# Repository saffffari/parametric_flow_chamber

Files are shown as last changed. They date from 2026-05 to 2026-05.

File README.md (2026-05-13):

# Parametric Flow Chamber

Open-source, parametric, parallel-plate perfusion flow chamber for delivering programmable wall-shear-stress waveforms to MLO-Y4 osteocyte-like cells on a Zeiss LSM 880 inverted multiphoton microscope. Includes hardware CAD, Teensy 4.1 firmware, and an Electron operator app with a synth-style control surface.

This repo is the companion to the paper. A first-time reader should be able to fabricate the chamber, flash the firmware, run the controller app, and reproduce paper figures from this single repository.

## Quickstart

| Goal | Path |
|---|---|
| Understand the science | [`docs/theory.md`](docs/theory.md) → [`docs/architecture.md`](docs/architecture.md) |
| Run the wet-lab protocol | [`docs/protocol.md`](docs/protocol.md) |
| Fabricate the chamber | [`hardware/bom.md`](hardware/bom.md) → [`hardware/assembly.md`](hardware/assembly.md) → [`hardware/machining_notes.md`](hardware/machining_notes.md) → vendor PDFs in [`hardware/drawings/`](hardware/drawings) |
| Flash the firmware | [`firmware/README.md`](firmware/README.md) |
| Run the operator app | [`app/README.md`](app/README.md) |
| Reproduce a paper figure | [`docs/reproducing.md`](docs/reproducing.md) (TBD) |

## What this is

A laminar parallel-plate perfusion chamber where the operator dials a single wall-shear-stress waveform in physical units (Pa). All other engineering quantities — flow rate, step pulse rate, microstepping, motor current — derive from chamber geometry, media viscosity, and the shear setpoint. The operator never sees an RPM.

The chamber:

- 316L stainless body, electropolished and passivated wetted surfaces.
- 24 mm × 50 mm × 0.25 mm channel under a Thorlabs CG15KH1 #1.5H cover glass.
- Inverted-microscope geometry: cells on the cover-glass floor, objective images from below.
- Autoclavable. No RTV silicone. No acetoxy-cure adhesives.

The controller:

- Teensy 4.1 + TMC2209 stepper driver running PlatformIO firmware.
- Inline liquid flow measurement via Sensirion SLF3S-1300F (PEEK-wetted, in the controller body, reports flow rate + media temperature on the same I²C frame).
- Closed-loop control on wall shear stress via direct flow + Hagen-Poiseuille geometry mapping.
- Optically-isolated BNC trigger to/from the microscope.
- microSD log of every sample, time-aligned with each LSM 880 frame.

In-loop measurement is via direct liquid flow (SLF3S-1300F). The differential-pressure approach is described in the methods section as a one-time per-chamber validation step, not as a deployed-device sensor; see `docs/protocol.md` for the validation procedure and `hardware/electronics/README.md` for the architecture.

The app:

- Electron + React + TypeScript with a synth-style control panel (OSC / SHEAR / ENV / DISPLAY / SYNC / TRANSPORT / MASTER).
- Mock-first: full development without hardware.
- Folder-based study persistence (JSON + CSV per run, no proprietary container).
- Mac (`.dmg`) and Windows (`.exe`/`.msi`) builds.

## Repo layout

- `docs/` — theory, architecture, protocol, design language, reproducing-a-figure recipes
- `hardware/` — BOM, assembly, machining notes, CAD source + STEP + drawings, electronics
- `firmware/` — PlatformIO project for Teensy 4.1
- `app/` — Electron + React + TypeScript operator app
- `examples/` — sample folder-based study and figure-regen scripts
- `.github/` — issue templates and CI workflows

## Status

This is the v2.0 release: the first public release. v1.0 was an undergraduate honors thesis prototype (Saffari, Cornell, 2024) that was not publicly released; v2.0 is a full rebuild with a parametric CAD source, a deterministic-timing firmware, and a new operator app on the Electron stack. See [`CHANGELOG.md`](CHANGELOG.md).

## Citing this work

If you use this chamber, the firmware, the app, or methods derived from this repository in academic work, please cite both the paper and the software archive.

**Software** (this repository):

```
Saffari, A., Rocca, I., Matthews, M., & Lewis, K. (2026).
Parametric Flow Chamber (v2.0).
[DOI / GitHub URL TBD on publication]
```

**Paper** (the methods paper this repository accompanies): TBD on publication.

A machine-readable citation file is in [`CITATION.cff`](CITATION.cff). GitHub renders the "Cite this repository" button from it.

## License

- **Code** (`firmware/`, `app/`, scripts in `examples/`): [MIT License](LICENSE).
- **Hardware and documentation** (`hardware/`, `docs/`, `examples/figures/`): [Creative Commons Attribution 4.0 International](LICENSE-HARDWARE).

These are the standard JOSS-aligned pair for open-source hardware companions to academic papers. You may use, modify, fabricate, and redistribute under these terms; please give appropriate credit and indicate any changes you made.

## Contributing

Issues and pull requests are welcome — see [`CONTRIBUTING.md`](CONTRIBUTING.md). Use the issue templates for bug reports, feature requests, and hardware questions.

## Acknowledgements

Cell line: MLO-Y4 (Bonewald lab, U. Missouri-Kansas City; gift; Lu et al. 2012). In vivo loading framework: Lewis et al. 2017 (Cornell). Machining: vendor TBD. Microscopy: Cornell Imaging Facility.

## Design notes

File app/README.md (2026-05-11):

# Flow Chamber operator app

Electron + React + TypeScript operator app for the parametric flow chamber. Drives the Teensy 4.1 firmware over USB serial, manages folder-based studies (JSON + CSV per run), and exposes a synth-style control surface in a Drams/Rams-influenced visual language.

## Stack

- **Electron 33** + electron-forge (with Vite plugin) — shell, packaging, signing
- **React 18 + TypeScript + Vite** — renderer
- **Tailwind v4** + Radix UI primitives + shadcn-style components — UI
- **motion** — animations, rotating-wheel inertia
- **Zustand** — app state (studies, runs, UI)
- **uPlot** — real-time telemetry plotting (~50 KB, made for streaming)
- **serialport** — Teensy serial; works on Mac (`/dev/cu.usbmodem*`) and Windows (`COM*`)
- **fs-extra + csv-parse** — study folder I/O
- **electron-store** — settings persistence
- **Vitest** + **Playwright** — unit + E2E testing

## Develop

```bash
cd app
npm install
npm start     # electron-forge start — launches the app in dev mode with hot reload
```

The dev build defaults to **mock mode**: a simulated Teensy interface produces realistic shear-vs-time waveforms (sine, square, triangle, DC). No hardware required.

## Build

```bash
npm run make
```

Builds platform-native installers under `out/make/`:

- macOS: `.dmg` (Intel + Apple Silicon)
- Windows: `.exe` (Squirrel) and `.msi`

## Test

```bash
npm run typecheck      # tsc --noEmit
npm run lint           # ESLint
npm run test:unit      # Vitest
npm run test:e2e       # Playwright
```

## Architecture

(Stubs only at this point — implementation per `planning/HANDOFF.md` § "v1 app scope (trimmed first slice)" follows in subsequent sessions.)

```
app/
├── electron/             # main process + preload
│   ├── main.ts           # window lifecycle, IPC handlers, native module bridge
│   └── preload.ts        # contextBridge API surface to the renderer
├── src/                  # renderer (React)
│   ├── main.tsx          # React entry
│   ├── App.tsx           # root shell (sidebar + main + footer)
│   ├── components/       # UI components (control panel blocks, knobs, widgets)
│   ├── domain/           # shear math, storage schemas, run lifecycle
│   ├── lib/              # mock interface, serial transport, study I/O
│   └── styles/           # globals.css with design tokens
├── tests/                # Vitest + Playwright tests
├── forge.config.ts       # electron-forge packaging config
├── vite.{main,preload,renderer}.config.ts
└── tsconfig.json
```

## Mock vs hardware mode

`app/src/lib/mock-interface.ts` is the in-process simulator. It produces realistic telemetry for development without the Teensy. The same interface can be backed by `app/src/lib/serial-interface.ts` (real Teensy via `serialport`) when running against hardware.

The HANDOFF v1 scope ships **mock-only**. Real serial connectivity ships in v2 once the firmware command set is finalized.

## Folder-based study format

Studies persist as folders containing JSON + CSV. The wire format is identical to the Python v0.1 controller (preserved at `archive/flow_chamber_v1/python_v0.1_app/` — outside the public repo) so old and new tooling cross-read. Sample at `examples/demo_study/`.

## Design language

See `docs/design_language.md`. Hardware aesthetic: TX-6-influenced precision instrument. Software aesthetic: Drams/Rams sibling visual language. Tokens come from the project Figma file (file key `J3aZzdLaJmidPQcOxphPdE`, root frame node `2004-140`) via the Figma MCP — replace placeholder values in `src/styles/globals.css` once authenticated.

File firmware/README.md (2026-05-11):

# Flow Chamber Teensy Firmware

Dry bench firmware for the Teensy 4.1 controller. This first target only proves
the Teensy, USB serial, onboard LED, and onboard microSD logging. It does not
drive fluidics.

## Hardware For This Step

- Teensy 4.1
- USB cable
- microSD card in the Teensy 4.1 onboard socket, optional but recommended

Do not connect the pump, TMC2209, or microscope trigger during this first smoke
test.

## Build And Upload

This project uses PlatformIO. A local PlatformIO environment has been created in
`.venv`, so these commands work even if `pio` is not globally installed:

```powershell
cd "D:\research\parametric flow chamber\firmware"
.\.venv\Scripts\pio.exe run -e teensy41
.\.venv\Scripts\pio.exe run -e teensy41 -t upload
.\.venv\Scripts\pio.exe device monitor -b 115200
```

During upload, press the Teensy program button if PlatformIO/Teensy Loader asks
for it.

## Serial Smoke Test

Open the serial monitor at `115200` baud and send:

```text
PING
STATUS?
LOGTEST
STOP
```

Expected responses:

```text
PONG flow_chamber_teensy_smoke 0.1.0
OK name=flow_chamber_teensy_smoke version=0.1.0 state=READY ...
OK wrote SMOKE00.CSV
OK pump outputs disabled
```

The onboard LED should blink twice per second. If a microSD card is present, the
firmware creates `SMOKE00.CSV`, `SMOKE01.CSV`, etc. with heartbeat rows.

## Dry STEP Test

Before wiring the TMC2209 or pump, verify the STEP output with a logic analyzer:

- logic analyzer `GND` to Teensy `GND`
- logic analyzer channel 0 to Teensy pin `2`

Commands:

```text
STEPTEST 100 5000
STATUS?
STEPTEST 1000 5000
STOP
```

`STEPTEST` pulses pin `2`, but keeps the TMC2209 enable pin disabled. The second
argument is duration in milliseconds. The firmware auto-stops after the duration.

## Dry Motor Jog

Only use `JOG` after the TMC2209 is wired correctly, current is set low, the 24 V
rail is fused, and no tubing or liquid is installed.

Initial command:

```text
JOG 100 3000
STOP
```

`JOG` enables the TMC2209 enable pin, pulses STEP, and auto-stops after the
requested duration. Duration is capped at 30 seconds. Use `DIR 0` or `DIR 1` to
change direction, but only while stopped.

## Safety Defaults

Pin 4 is configured as the future TMC2209 `ENABLE` pin and is driven disabled on
boot. Most TMC2209 carrier boards use active-low enable, so this firmware drives
that pin high and reports `pump=disabled` in `STATUS?`.

Command safety behavior:

- `STOP` ends the timer and drives TMC2209 `ENABLE` disabled.
- `STEPTEST` never enables the driver.
- `JOG` is time-limited and auto-stops.
- Direction changes are rejected while step pulses are active.

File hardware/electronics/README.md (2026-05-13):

# Electronics — controller, pressure, and bring-up

> Merged from `electronics_controller_architecture.md`, `chamber_pressure_system.md`, and `electronics_bringup_checklist.md` from the dev archive. Section dividers (`---`) preserve source boundaries; source heading levels demoted by one level.

## Contents

1. **Controller Architecture** — Teensy 4.1 + TMC2209 stepper driver + isolated BNC trigger interface; pump control strategy; safety architecture; tentative Teensy pin map; firmware module layout.
2. **Flow & Shear Measurement System** — Sensirion SLF3S-1300F inline liquid flow sensor in the controller; closed-loop shear stabilization via flow + Hagen-Poiseuille geometry mapping; pulsation dampeners; digital twin; LSM 880 frame-marker time alignment; calibration protocol. Per-chamber validation against a separate gas-side differential-pressure rig (DFRobot SEN0343 / All Sensors LWLP5000 + standpipes + Millex-FG separators) is described under "Validation methodology" and `docs/protocol.md` § "Per-chamber sensor validation".
3. **Bench Bring-Up Checklist** — the procedural test sequence; bench setup table; suggested first wiring map; pump calibration; microscope trigger validation; wet-run gate.

> **Cross-references:** body sections reference `design_spec_v2.md` (split → `docs/theory.md` + `docs/architecture.md`) and `Sensor Survey for Wall Shear Stress.md` (moved → `literature/sensor_survey_wall_shear.md`). In-body cross-references have **not** been updated.

> **Geometry note:** the pressure-system section uses the canonical 24 mm × 50 mm × 0.25 mm geometry with μ = 0.9 mPa·s. The bring-up section is geometry-independent.

---

## Electronics And Controller Architecture

This document is the working controller design for the open-source flow chamber. It supersedes the electronics assumptions in `2photon_flow_chamber_v2.md` where the two conflict.

Goal: make the chamber behave like a small research instrument, not a pile of lab electronics. The controller must deliver repeatable shear stimulus, log the exact stimulus timing, and remain buildable by an undergraduate lab. Microscope protection comes from chamber design (sealed, autoclavable, no exposed electrodes) and operator-side visual monitoring; dedicated leak detection is out of scope for the current spec.

### Primary Decision

Use the Teensy 4.1 as the real-time controller.

Use the ESP32-S3 only as an optional wireless/status coprocessor later. It should not own pump timing, microscope trigger timing, or the authoritative experiment log.

Why:

- Teensy 4.1 has deterministic timers, native high-speed USB, onboard microSD, many serial/SPI/I2C ports, and enough GPIO for this system.
- ESP32-S3 is excellent for WiFi/BLE, but wireless and RTOS scheduling should not sit in the critical path for pump timing or safety shutdown.
- The open-source reference build should work without WiFi, cloud services, or network configuration.

### System Roles

| Function | Primary implementation | Notes |
|---|---|---|
| Pump timing | Teensy 4.1 hardware timer | Step pulse generation must not depend on laptop timing |
| TMC2209 configuration | Teensy UART | Current, microstepping, diagnostics |
| Flow protocol engine | Teensy state machine | Baseline, ramp, hold, recovery |
| Temperature logging | DS18B20 probes on Teensy OneWire | Reservoir, inlet, ambient/stage |
| Pump shutdown | Hard 24 V enable cut + firmware STOP | Physical switch/fuse on the motor rail; firmware-side STOP disables the TMC2209 ENABLE pin |
| Microscope sync | Isolated BNC trigger board | The i880 interface must remain electrically isolated |
| Experiment log | Teensy microSD | Teensy timestamp is authoritative |
| Live GUI | Laptop over USB serial | Optional for run control and plotting |
| Local display | Waveshare OLED on Teensy SPI | Useful for standalone status |
| Wireless mirror | ESP32-S3 optional | Telemetry viewer only, not safety-critical |

### Practical Electrical Architecture

The original notes proposed three fully galvanically isolated domains. That is the right instinct for the microscope, but it is too easy to claim false isolation with a commodity TMC2209 module.

Most TMC2209 carrier boards tie motor ground and logic ground together. If the Teensy drives the TMC2209 while both boards share ground, optocouplers on STEP/DIR do not create real galvanic isolation. True motor-domain isolation would require:

- an isolated DC/DC supply for the motor-driver logic side;
- isolators on every signal crossing: STEP, DIR, ENABLE, UART TX/RX, DIAG if used;
- a driver carrier or custom board whose logic reference can actually remain separate;
- no shared USB, shield, sensor, or chassis path between domains.

For the first paper-grade build, use this more defensible split:

1. **Logic/motor domain inside the controller box**
   - Teensy, TMC2209, display, sensors, and 24 V motor driver live in one controlled enclosure.
   - Tie logic ground and motor ground at a deliberate star point near the power entry/driver.
   - Keep motor wiring physically separated from analog/trigger wiring.
   - Use local bulk capacitance and fusing on the 24 V rail.

2. **Microscope domain isolated absolutely**
   - No direct electrical connection from Teensy ground to the i880 trigger BNC shield or center conductor.
   - Use optocoupler or digital isolator circuitry for trigger OUT and trigger IN.
   - Test the isolated trigger board on the bench before connecting to the microscope.

3. **Fluidic/chamber metal kept electrically passive**
   - Do not intentionally bond chamber steel to Teensy ground.
   - Do not put powered sensors in the wetted fluid path.

This is simpler, safer, and easier to explain in an open-source build guide.

### Block Diagram

```mermaid
flowchart LR
    Laptop["Laptop GUI<br>USB serial"] --> Teensy["Teensy 4.1<br>real-time controller"]
    Teensy --> SD["microSD<br>experiment log"]
    Teensy --> OLED["1.5 in OLED<br>local status"]
    Teensy --> Temp["DS18B20 probes<br>reservoir/inlet/ambient"]
    Teensy --> TMC["TMC2209 stepper driver"]
    PSU["24 V fused supply<br>hard E-stop"] --> TMC
    TMC --> Pump["Stepper peristaltic pump"]
    Teensy --> IsoOut["Isolated trigger OUT"]
    IsoOut --> I880["Zeiss LSM 880 trigger interface"]
    I880 --> IsoIn["Isolated trigger IN"]
    IsoIn --> Teensy
    ESP32["ESP32-S3 optional<br>wireless mirror"] -. telemetry only .-> Laptop
    Teensy -. serial telemetry .-> ESP32
```

### Inventory Assessment

#### Use Now

| Item | Use | Action |
|---|---|---|
| Teensy 4.1 | Main controller | Lock as primary |
| Teensy terminal block breakout | Harness interface | Use for first wired build |
| TMC2209 drivers, qty 2 | Pump driver and spare/future second pump | Use one, keep one spare |
| 64 GB microSD | SD logging | Use onboard Teensy SDIO socket |
| DS18B20 probes, qty 5 | Temperature logging | Use 3 initially; keep spares |
| 4.7k resistors | OneWire pull-up | Use one from DQ to 3.3 V |
| RGB OLED 1.5 in | Local status panel | Prefer this for colored state cues |
| EC11 encoders | Local control | Use one primary encoder with push button |
| Logic analyzer | Bring-up | Verify STEP frequency, UART, trigger timing |
| Fuse holders and blade fuses | 24 V motor rail | Use 1 to 2 A fuse to start, adjust after pump current is known |
| Ferrules, heat shrink, silicone wire | Harnessing | Use for final wiring |
| Ferrule crimper | Harnessing | Use with ferrules before landing stranded wire in screw terminals |

#### Use Later Or Optional

| Item | Recommendation |
|---|---|
| ESP32-S3 N16R8 | Optional wireless dashboard/logger mirror. Do not use as the real-time controller. |
| Grayscale OLED | Backup display or secondary diagnostic display. Not needed initially. |
| LIS3DSH accelerometers | Optional pump vibration and stage disturbance logging. The part is out of production, so do not make it a required open-source component. |
| I2S MEMS microphone | Not part of the core flow chamber. Only consider later for exploratory acoustic pump diagnostics. |

#### Missing Before Full Controller Build

| Item | Why it matters |
|---|---|
| Confirmed pump and stepper wiring | Motor current, steps/rev, connector, and tubing calibration drive firmware constants |
| 24 V DC power supply | Required for pump/TMC2209 |
| Isolated BNC trigger board parts | Protects the i880 and the laptop from ground-loop paths |
| Enclosure and panel hardware | No loose breadboard on the microscope |
| E-stop or latching motor-power switch | Physical pump shutdown independent of firmware |
| TMC2209 heatsink / airflow plan | Avoid driver thermal faults |
| Multimeter and ideally oscilloscope access | Logic analyzer is enough for digital timing, but analog voltage checks still matter |

### Recommended Controller Enclosure

Make the electronics box a separate TX-6-inspired instrument:

- satin metal or light polymer enclosure;
- small OLED top/right;
- one encoder for setpoint selection;
- three buttons: `prime`, `run`, `stop`;
- small orange indicator for `flow active` or `alarm`;
- BNC trigger connector on one side;
- separate motor, sensor, and USB exits;
- no loose Dupont jumpers after bring-up.

The controller enclosure does not need to fit on the microscope stage. Keep it off-stage with strain-relieved harnesses.

### Trigger Interface

The Zeiss LSM 880 trigger interface is the one place to be conservative.

A public LSM 880 operating manual mirror describes the trigger interface as 3.3 V TTL, tolerant of 5 V logic, with output load below 50 mA, a 68 ohm internal series resistor on output, and a 4.7k input pull-up to 3.3 V. It also notes that standard BNC cables are used through the optional user interface box.

Use that as a design hint, not a facility guarantee. Confirm the actual Cedars-Sinai i880 trigger box before connecting.

Recommended isolated trigger board:

| Direction | Circuit | Default behavior |
|---|---|---|
| Teensy to i880 TriggerIN | Optocoupler transistor on microscope side | Open-collector pull-down pulse, no shared ground |
| i880 TriggerOUT to Teensy | Optocoupler LED driven by BNC signal through resistor | Teensy interrupt pin sees isolated pulse |

Bench validation:

1. Verify no continuity between Teensy ground and BNC shield.
2. Drive TriggerOUT circuit from a 3.3 V test signal and inspect Teensy pin with logic analyzer.
3. Drive TriggerIN circuit from Teensy and inspect BNC side with a pull-up/resistor test load.
4. Only then connect to the microscope with core staff present.

PC817-class optocouplers are acceptable for run-start markers and 2 to 6 Hz frame/event markers. They are not appropriate for pixel clock, line clock, or nanosecond timing.

### Pump Control Strategy

The pump should be stepper-driven through TMC2209 in STEP/DIR mode. UART configures the driver; the Teensy timer generates STEP pulses.

Use 16x or 32x external microstepping and let the TMC2209 interpolate internally to 256 microsteps. Do not default to true 256x STEP input unless the measured step frequency remains comfortably low.

Core formula:

```text
step_rate_hz = flow_ml_min * calibrated_steps_per_ml / 60
```

Where:

```text
calibrated_steps_per_ml =
    motor_full_steps_per_rev * external_microsteps * pump_revs_per_ml
```

The constant must be measured gravimetrically for the actual pump head and tubing. Do not trust catalog flow curves for paper-grade shear stress.

Required pump states:

- `DISABLED`: TMC disabled, motor power present but no drive.
- `IDLE`: driver configured, pump stopped, ready.
- `RAMPING`: changing flow with bounded acceleration.
- `HOLDING`: constant target flow.
- `FAULT`: driver fault, SD failure, or explicit emergency stop.

Stimulus modes to support from the start:

- baseline no-flow period;
- ramp to target flow;
- hold target flow;
- ramp to zero;
- repeated pulses;
- later: sinusoidal or frequency-coded shear for Lewis-style mechanotransduction experiments.

### Safety Architecture

Safety should not depend only on code.

Hardware:

- fuse the 24 V rail close to power entry;
- use a latching motor-power switch or E-stop that removes 24 V from the TMC2209;
- add a pull-up so TMC `ENABLE` defaults disabled during reset;
- keep pump motor cable away from BNC and sensor wiring;
- keep all breadboards away from wet microscope operation.

Firmware:

- enable the watchdog;
- boot into pump disabled;
- refuse flow commands until sensors, SD, and driver config pass startup checks;
- shut down pump immediately on driver overtemperature, serial protocol fault during a run, or SD write failure if logging is required;
- require explicit user reset after any E-stop event.

### Temperature Sensing

Use DS18B20 probes as slow environmental sensors, not as fast thermal control feedback.

Initial channels:

- reservoir media;
- tubing immediately before the chamber, external contact or small non-wetted pocket;
- ambient/stage air near chamber;
- optional outlet/reservoir return.

Implementation notes:

- power sensors from 3.3 V, not parasite power;
- use one 4.7k pull-up from OneWire data to 3.3 V;
- map each probe's 64-bit ID to its physical location in a config file;
- request all conversions asynchronously and read back after the conversion interval;
- log at 1 Hz.

At 12-bit resolution, DS18B20 conversion time is up to 750 ms. That is fine for experiment metadata and slow drift, not for fast thermal transients.

### Optional Accelerometer Use

The LIS3DSH modules can be useful during engineering validation:

- mount one on the pump body to quantify roller/stepper vibration;
- mount one near the stage/chamber holder to detect whether pump motion is coupling into the microscope;
- log synchronized acceleration during no-flow and flow runs.

Do not include LIS3DSH in the required open-source BOM because ST lists the part as obsolete/out of production.

### Display And Manual UI

Use the RGB OLED for the main controller status because the color channel can communicate state without text-heavy UI.

Minimal local screen:

```text
FLOW  4.34 ml/min
SHEAR 1.00 Pa
TEMP  36.8 C
LOG   00:12:44
STATE HOLDING
```

Manual controls:

- encoder rotates selected value;
- encoder press switches field;
- `prime` runs low-speed pump until released or timed out;
- `run` starts loaded protocol;
- `stop` enters safe pump-disabled state.

The laptop GUI remains the main setup surface. The local UI is for priming, status, and emergency clarity.

### Revised Tentative Teensy Pin Map

Final firmware should put these in `hardware_config.h`.

| Teensy pin | Function | Notes |
|---:|---|---|
| 0 RX1 | TMC2209 UART RX | Direct if shared motor/logic ground; isolated only in full isolation build |
| 1 TX1 | TMC2209 UART TX | 115200 baud start point |
| 2 | TMC2209 STEP | Timer-driven output |
| 3 | TMC2209 DIR | Direction output |
| 4 | TMC2209 ENABLE | Use pull-up so driver defaults disabled |
| 5 | i880 trigger OUT LED drive | Drives isolated output board |
| 6 | i880 trigger IN isolated output | Interrupt-capable input |
| 7 | Reserved | Free for future use |
| 8 | OLED RST | SPI display |
| 9 | OLED DC | SPI display |
| 10 | OLED CS | SPI display |
| 11 | SPI MOSI | OLED, optional SPI sensors |
| 12 | SPI MISO | Optional diagnostics/sensors |
| 13 | SPI SCK | OLED; also onboard LED pin, acceptable |
| 14 / A0 | Reserved analog in | 0 to 3.3 V only; free for future use |
| 15 / A1 | Reserved analog in | 0 to 3.3 V only; free for future use |
| 16 / A2 | Reserved analog in | 0 to 3.3 V only; free for future use |
| 17 / A3 | Reserved analog in | 0 to 3.3 V only; free for future use |
| 18 SDA | I2C optional | LIS3DSH or future sensors |
| 19 SCL | I2C optional | LIS3DSH or future sensors |
| 20 | OneWire DS18B20 bus | 4.7k pull-up to 3.3 V |
| 21 | Buzzer or alarm LED | Optional, add if purchased |
| 22 | TMC DIAG/fault | Optional driver diagnostic input |
| 24 | Encoder A | Local UI |
| 25 | Encoder B | Local UI |
| 26 | Encoder switch | Local UI |
| 28 | Pump 2 STEP | Reserved for second driver |
| 29 | Pump 2 DIR | Reserved |
| 30 | Pump 2 ENABLE | Reserved |

Important: Teensy 4.1 pins are 3.3 V only and not 5 V tolerant. Any external 5 V signal must be level shifted or isolated.

### Firmware Architecture

Use cooperative state machines plus timer interrupts.

Modules:

- `hardware_config.h`: pins, constants, calibration.
- `pump_control`: TMC2209 init, step timer, ramp planner.
- `protocol_runner`: baseline/ramp/hold/recovery script engine.
- `sensors`: DS18B20, optional accelerometer.
- `trigger_io`: isolated BNC trigger in/out.
- `logger`: SD file creation, buffering, flush policy.
- `serial_protocol`: host commands and telemetry.
- `safety`: watchdog, fault latch, shutdown rules.

Timing rules:

- STEP pulse generation runs from a hardware timer.
- Trigger edge timestamp is captured immediately.
- SD writes never happen inside interrupts.
- USB serial is never allowed to block the control loop.
- Sensor polling is scheduled and nonblocking where possible.

### Serial Protocol Direction

For first bring-up, use line-oriented text commands because they are debuggable with any serial terminal:

```text
PING
SET FLOW 4.34
SET SHEAR 1.00
RUN protocol_name
STOP
PRIME 2.0
TRIGGER 10000
STATUS?
```

Telemetry can start as CSV or line-delimited JSON at 10 Hz. This is more open-source-friendly than an early binary protocol and is easily fast enough over Teensy native USB.

A binary framed protocol can be added later if telemetry expands to high-rate acceleration or multiple pumps.

### Logging

The SD log should be self-contained enough to analyze without the GUI.

Minimum CSV columns:

```text
timestamp_us,run_time_s,state,flow_setpoint_ml_min,shear_setpoint_pa,
step_rate_hz,temp_reservoir_c,temp_inlet_c,temp_ambient_c,
trigger_count,event_flags,fault_code
```

Also write a run metadata file:

- channel width/height/length;
- viscosity assumption;
- calibrated steps_per_ml;
- protocol name;
- software version;
- DS18B20 probe ID map;
- operator notes if passed from GUI;
- microscope configuration note.

### Bring-Up Sequence

Do this in order.

1. **Teensy smoke test**
   - Blink, serial console, SD card create/write/read.
   - Confirm 3.3 V rail stable.

2. **Display and encoder**
   - OLED status screen.
   - Encoder scrolls a dummy setpoint.

3. **DS18B20**
   - Read all probes.
   - Record probe IDs and physical labels.

4. **TMC2209 dry driver test**
   - No pump tubing, motor unloaded.
   - Configure current low.
   - Verify STEP frequency with logic analyzer.

5. **Pump rotation**
   - Confirm direction, enable polarity, no thermal fault.
   - Add current limit and heatsink.

6. **Isolated trigger board**
   - Bench-test no-continuity and pulse behavior.
   - Do not connect to microscope yet.

7. **Integrated dry run**
   - Run full protocol with pump disconnected from fluid.
   - Verify log file, state transitions, trigger timestamps.

8. **Water loop test**
   - Run with water off-microscope.
   - Calibrate flow gravimetrically.
   - Visually monitor every fitting and the chamber-to-cover-glass interface for drips. Wipe-test with a paper towel under the loop.
   - Tune ramp rates.

9. **Microscope trigger validation**
   - With core staff, connect only the isolated BNC board.
   - Verify ZEN receives marker or sends trigger as expected.

No wet microscope run until steps 1 through 9 are complete.

### First Firmware Milestone

Target: motor moves under Teensy control and logs timing.

Minimum feature set:

- USB serial command: `SET FLOW <ml_min>`;
- USB serial command: `STOP`;
- timer-generated STEP pulses;
- OLED showing setpoint and state;
- SD CSV with timestamp, state, setpoint, and step rate;
- TMC ENABLE defaults disabled until explicit run command.

This milestone proves the timing backbone without requiring chamber machining or microscope access.

### Ambitious Later Extensions

These are worth planning for, but not blocking RapidDirect:

- second pump channel for donor/receiver conditioned-media experiments;
- motor phase logging to correlate peristaltic ripple with calcium artifacts;
- waveform shear protocols: pulses, ramps, sinusoidal, frequency sweeps;
- ESP32-S3 wireless dashboard for remote status outside the microscope room;
- simple web export of run logs plus microscope acquisition timestamps.

### Primary Sources Checked

- PJRC Teensy 4.1 specifications: https://www.pjrc.com/store/teensy41.html
- Analog Devices / Trinamic TMC2209 product page and datasheet links: https://www.analog.com/en/products/tmc2209.html
- Analog Devices DS18B20 product page and datasheet links: https://www.analog.com/en/products/ds18b20.html
- Espressif ESP32-S3-WROOM-1 datasheet: https://documentation.espressif.com/esp32-s3-wroom-1_wroom-1u_datasheet_en.pdf
- Waveshare 1.5 inch OLED module wiki: https://www.waveshare.com/wiki/1.5inch_OLED_Module
- Waveshare 1.5 inch RGB OLED module wiki: https://www.waveshare.com/wiki/1.5inch_RGB_OLED_Module
- ST LIS3DSH product page: https://www.st.com/content/st_com/en/products/mems-and-sensors/accelerometers/lis3dsh.html
- Adafruit SPH0645 I2S microphone guide: https://learn.adafruit.com/adafruit-i2s-mems-microphone-breakout
- Public LSM 880 operating manual mirror for trigger-interface details: https://www.manualslib.com/manual/1239435/Zeiss-Lsm-880.html

---

## Chamber Pressure And Shear Verification System

This document defines the in-loop sensing stack that measures wall shear stress on the cells during a flow experiment. It supersedes the simpler "two pressure sensors at the luer ports" sketch I had been using earlier in the architecture doc and incorporates the analysis in `Sensor Survey for Wall Shear Stress.md`.

Related docs: `README.md`, `design_spec_v2.md`, `rapid_direct_design_lock.md`, `electronics_controller_architecture.md`, `electronics_bringup_checklist.md`, `microscope_i880_constraints.md`, `Sensor Survey for Wall Shear Stress.md`.

### Purpose

Wall shear stress on the cells is the primary experimental variable for the calcium-flux work. The bone mechanotransduction literature almost universally reports shear as a calibrated pump RPM with no in-loop verification. This system measures shear continuously during every confocal frame via a direct inline liquid flow measurement (Sensirion SLF3S-1300F, PEEK-wetted, sits in the controller body downstream of the pump), mapped to wall shear via the locked Hagen-Poiseuille channel geometry. Each chamber is also characterized once before deployment against an independent gas-side differential-pressure measurement (DFRobot SEN0343 / LWLP5000 ±500 Pa with temporary standpipes + Millex-FG hydrophobic separators) to validate the SLF3S response — that calibration figure is the methods-paper deliverable, after which the validation rig is removed and only the SLF3S runs in the deployed loop. The chamber goes from "we calibrated the pump" to "shear is measured live, time-aligned with each LSM 880 frame, and cross-validated against an independent physics-based measurement per chamber."

### Operating window

For our locked chamber geometry (**w = 24 mm, h = 0.25 mm, L = 50 mm**, channel taking the full Thorlabs CG15KH1 cover-glass footprint) and culture-medium viscosity μ ≈ 0.9 mPa·s at 37 °C (DMEM/α-MEM with serum, per Poon et al. range of 0.83–0.95 mPa·s), wall shear stress, volumetric flow, and channel pressure drop are linked by:

```text
τ_w = 6 μ Q / (w h²)         (shear from flow)
ΔP/L = 12 μ Q / (w h³)        (pressure drop from flow)
τ_w = ΔP · h / (2 L)         (shear directly from ΔP)
```

The relevant operating envelope:

| Target shear (Pa) | Target shear (dyn/cm²) | Required Q (mL/min) | ΔP across 50 mm (Pa) | ΔP (mbar) |
|---|---|---|---|---|
| 0.5 | 5 | ~8.3 | 200 | 2.0 |
| 1.0 | 10 | ~16.7 | 400 | 4.0 |
| 2.0 | 20 | ~33.3 | 800 | 8.0 |
| 5.0 | 50 | ~83.3 | 2 000 | 20 |
| 10 | 100 | ~166.7 | 4 000 | 40 |

The MLO-Y4 calcium-flux literature operates almost entirely in the 0.5–4 Pa band (Lu et al. 2012; Huo/Guo 2012; Kamioka et al. 2006; the Lewis 2017 framework), with peak excursions to ~5 Pa for process-level mechanotransduction. The practical target window is **τ_w = 0.5–10 Pa, Q ≈ 10–215 mL/min, ΔP ≈ 0.2–4 kPa across the 50 mm channel**.

Reynolds number stays below ~25 across the entire window. The flow is laminar, fully developed within ~0.3 mm of the inlet, and Hagen-Poiseuille applies.

### Architecture decision

**Single-sensor shear measurement via inline liquid flow, cross-validated per chamber against an independent gas-side differential-pressure rig.**

**Deployed device sensor — Sensirion SLF3S-1300F.** Inline liquid flow sensor, PEEK-wetted, biocompatible. Sits in the controller body downstream of the peristaltic pump and upstream of the chamber inlet. Reports volumetric flow rate (in mL/min) and media temperature on the same I²C frame, at up to ~1–2 kHz fast-mode sample rate. Closed-loop control runs on flow: the controller maps target wall shear stress to required flow rate via the locked Hagen-Poiseuille geometry, then closes a PID on the SLF3S reading. CIP-cleaned between experiments per `docs/cleaning_protocol.md`; never autoclaved.

**Per-chamber validation rig (one-time, bench instrument, not in BOM).** DFRobot SEN0343 (All Sensors LWLP5000 ±500 Pa differential pressure, I²C) read by a Raspberry Pi Pico 2 on a half-size breadboard. Gas-side measurement via temporary standpipes attached to dedicated pressure-tap ports on the chamber, with Millipore Millex-FG (PTFE) 0.22 µm hydrophobic membrane separators holding the liquid/gas interface. Used once per chamber before deployment to characterize the SLF3S response by simultaneous logging of SLF3S Q and SEN0343 ΔP across a flow sweep, fitting the regression to confirm slope ≈ 1.00 against the Hagen-Poiseuille prediction. The procedure lives in `docs/protocol.md` § "Per-chamber sensor validation". After the calibration certificate is captured the standpipes are removed, the pressure-tap ports plugged, and only the SLF3S runs during cell experiments.

Wall shear comes from the inline flow measurement and the locked channel geometry:

```text
τ_w = 6 μ Q_measured / (w · h²)
```

with `w` and `h` known from the chamber drawing and verified by CMM after machining, μ = 0.9 mPa·s for the standard working medium. The Hagen-Poiseuille mapping introduces a viscosity assumption that the gas-side differential-pressure rig does not — that's why the cross-validation is done once per chamber against an independent physics-based measurement.

**What the SLF3S covers in deployment**:

| Signal | Mechanism |
|---|---|
| Wall shear stress (real-time) | τ_w = 6 μ Q / (w · h²), direct from flow |
| Media temperature in the controller-side loop | Free from the same I²C frame as the flow read |
| Bubble in line | Sharp negative-going Q transient + sensor's onboard bubble-detect flag (logged) |
| Blockage | Pump command active but Q reads near zero |
| Leak between pump and chamber | Inconsistency between flow setpoint and observed Q |
| Pump stall | Step command active but Q near zero |
| Reservoir empty | Step command active, Q collapses, bubble flag fires |
| Stimulus onset timing | Rising edge of Q, ms-resolved, Teensy-timestamped |
| Peristaltic pulsation harmonics | Fast-mode sampling at ~100–1000 Hz captures fundamental + harmonics |
| Calibration drift over time | Q at known pump command drifts from at-bench-calibrated baseline |

**What this architecture gains over the earlier differential-pressure-only design**:

- Direct measurement of the controller's primary control variable (flow), no viscosity assumption in the live measurement.
- Media temperature comes free in the same frame — useful for cross-checking incubator and chamber thermal stability.
- No standpipe maintenance burden during routine cell experiments. Standpipes only need to exist during the one-time validation pass.
- Cleaner sterile-loop story: the chamber alone is autoclaved; the SLF3S in the controller is CIP-cleaned between runs (`docs/cleaning_protocol.md`).

**What it loses relative to the older standpipe-and-SDP810 design**:

- Wall shear is now derived from flow + viscosity, not direct from ΔP. The viscosity assumption is a real error term — partially mitigated by the SLF3S temperature reading and the per-chamber validation against the independent ΔP rig.
- Continuous live ΔP-based verification during cell experiments. Recovered by the one-time validation figure and by periodic gravimetric re-calibration at the bench.

### Why this specific part

**Sensirion SLF3S-1300F** as the deployed in-loop flow sensor:
- 1300 mL/min full-scale range covers the operating window (8–167 mL/min at 0.5–10 Pa shear over the locked channel) with headroom for higher-shear excursions and CIP flush rates.
- ±5 % reading accuracy with factory zero. Combined with the per-chamber validation against the gas-side ΔP rig, total uncertainty on derived shear stays within ±5 %.
- I²C interface returns flow rate, fluid temperature, and a bubble-detect flag in the same frame. Driver lives in the standard Sensirion library stack.
- PEEK-wetted, biocompatible. CIP-cleaned per `docs/cleaning_protocol.md`; never autoclaved.
- Direct measurement of the variable the closed-loop controller most needs (flow), with the viscosity-dependent map to shear handled in software against the locked channel geometry.

**DFRobot SEN0343 (All Sensors LWLP5000 ±500 Pa diff pressure breakout)** as the validation instrument:
- ±500 Pa range matches the expected ΔP across the locked 50 mm channel at 0.5–1.25 Pa shear directly; reduced tap separation extends the range.
- ±1.5 % FSS accuracy — translates to constant ±7.5 Pa across the range, comparable to the SDP800-family parts at this band.
- I²C output through the breakout's pre-soldered pull-ups; mounts on a Pi Pico 2 breadboard rig that lives in lab inventory and is amortized across every chamber built.
- Gas-side measurement via standpipes + Millex-FG hydrophobic separators preserves chamber sterility during the validation pass.

**What we explicitly chose against**:
- **Bare Sensirion SDP810-500Pa** for the validation rig: equivalent ±500 Pa I²C diff pressure sensor, ±3 % reading accuracy, $30. Functionally fine; the SEN0343 wins on plug-and-play because the breakout includes pull-ups and a header, saving hand-soldering on an instrument used a handful of times per year.
- **Single-sensor SDP810 + standpipes as the deployed architecture** (the v1-era proposal): keeps the chamber autoclavable and the sensor gas-only, but adds standpipe maintenance burden during every cell experiment and introduces gas-column compliance / interface-oscillation effects that the SLF3S sidesteps. The SDP architecture is now used only during the one-time validation pass.
- **Inline flow sensors with shorter wetted-path lifetimes** (e.g. impeller / turbine): dead volume, particulate sensitivity, calibration drift — wrong for serum-containing cell media.
- **Honeywell ABP2 wet-wet at ±1 psi**: cleaner plumbing for ΔP, but ±1.5 % FSS on a ±6.9 kPa range is ~100 Pa total error band, marginal at 0.5 Pa shear (200 Pa ΔP) and unacceptable at 0.2 Pa.
- **TE MS5837-30BA × 2 with digital subtraction**: budget tier, viable for τ ≥ 2 Pa work but doesn't reach the bottom of the calcium-flux band.
- **Setra Model 230 wet-wet capacitive**: $700–$1,200, exceeds budget without proportional accuracy gain.
- **Coriolis (Bronkhorst, Emerson MicroMotion)**: gold-standard accuracy, $4,000+, far over budget.
- **Ultrasonic clamp-on (SONOTEC SONOFLOW)**: $1,500–$3,500, fully sterile but priced beyond a single-channel addition.
- **DIY hot-wire / custom MEMS wall-shear**: research-grade, fouling-prone in serum, not commercially available.

### Validation rig: pressure-tap and standpipe stack (one-time per chamber, methods only)

> This section describes the **bench-side validation instrument** used once per chamber before deployment to characterize the SLF3S response against an independent gas-side ΔP measurement. The standpipe stack is **not** part of the deployed device — the chamber's pressure-tap ports are plugged during routine cell experiments and the validation rig (Pi Pico 2 + DFRobot SEN0343 on a breadboard) lives in lab inventory between uses. See `docs/protocol.md` § "Per-chamber sensor validation" for the procedure.

The SEN0343 (LWLP5000) reads gas-side ΔP across the channel. Two optional pressure taps in the chamber connect via short PEEK risers to two vertical standpipes maintaining a clean liquid/gas interface. The sensor sees only gas above the interface.

**Pressure taps in the chamber body**: two 0.5 mm bores through the steel ceiling, perpendicular to the channel surface, located at axial positions 5 mm and 45 mm (40 mm separation, well inside the fully-developed region). Tap diameter <50 µm would be ideal for true static pressure measurement, but 0.5 mm is the practical machining limit and the geometric correction is small (~1 % of ΔP) and characterizable. Each tap has a 1/4-28 flat-bottom port on the topside of the steel for IDEX-compatible PEEK fittings; the ports are plugged with a 1/4-28 plug for routine cell experiments and only opened during the per-chamber validation pass.

**Riser tubing**: 1/16″ OD PEEK tubing from each tap rises ~50 mm to the standpipe inlet. PEEK because chemical resistance in the sterile loop matters and the small rise is rigid enough not to flex with peristaltic pulsation.

**Standpipes**: 50 mm tall × 4–6 mm ID clear cast acrylic or borosilicate glass tubes, vertical, with the bottom 30 mm filled with degassed media and the top 20 mm trapped gas. The SEN0343's two barbed ports tee off the gas column near the top via 1/16″ ID silicone tubing.

**Sealed-pocket sterile isolation**: a 0.22 µm hydrophobic membrane (Millex-FG, MilliporeSigma SLFG025LS, or equivalent) is plumbed inline between the bottom liquid column and the gas pocket above, isolating the gas from the wetted path. This is the primary sterile barrier during the validation pass — the gas above is microbiologically sealed from the media below.

**Geometry rationale**:
- 30 mm liquid headroom absorbs ±1–5 mm peristaltic interface oscillation without liquid carryover toward the sensor.
- 20 mm gas headroom is short enough that gas-column compliance does not attenuate the pulsation harmonics the sensor is meant to capture during the validation sweep.
- The two standpipes are mounted to the same insulated bracket, thermally coupled to each other, so any temperature drift is common-mode and rejected by the differential measurement.

**Standpipe failure modes during a validation pass**:
- Bubble migration up the riser into the standpipe corrupts ΔP. Mitigated by the inline membrane separator and by re-priming before each validation sweep.
- Inline membrane wetting failure (very rare with hydrophobic PTFE Millex-FG) would let liquid pass into the gas pocket. Caught at the next zero check (SEN0343 reads non-zero with pump off).
- Temperature gradient between standpipe and chamber creates a density mismatch and false ΔP offset. Mitigated by routing both standpipes through the same insulated bracket.

After the validation regression is captured and the certificate filed, the standpipe stack is disconnected, the chamber pressure-tap ports plugged, and the chamber reassembled for cell-experiment work driven by the SLF3S alone.

### Pulsation dampeners

A peristaltic pump with N rollers produces a flow waveform with fundamental frequency f = N · RPM / 60 Hz and harmonics. At our pump RPMs (10–100), this is 0.5–17 Hz — overlapping with calcium oscillation timescales (0.1–1 Hz). Without dampening, peristaltic pulsation can be ±10–30 % flow modulation at the roller frequency.

The published consensus (PMC3426609; PMC9508572) is that **two dampeners — one upstream of the chamber and one downstream — are required** to flatten pulsation in a closed loop. Three implementation tiers:

**DIY trapped-air compliance (recommended for v2)**: a 5 mL syringe body with the plunger fixed at mid-stroke, plumbed in-line via a 1/4-28 tee fitting. The trapped air acts as a capacitive low-pass filter. For 2.5 mL trapped air and 1 m of inlet/outlet tubing, the cutoff frequency is ~1 Hz, attenuating the pump fundamental (3–10 Hz) by ~10×. Gas dissolution into degassed media over hours requires a hydrophobic membrane separator — a Millex-FG (PTFE, 0.22 µm) inserted between the air pocket and the liquid path. Two assemblies, one upstream and one downstream of the chamber. **Cost: $5 each in parts.**

**Cole-Parmer Masterflex pulse dampener** (#07596-20 or similar): purpose-built, $80–150 each, $160–300 for the pair. Standard reference design used in commercial perfusion systems. No DIY characterization burden.

**Tokai Hit MiViVo-BPU style buffer chamber**: commercial constant-pressure dampener, ~$1,500. Achieves <1 mmHg residual pulsation. Reference ceiling, not a buy.

For the open-source build, the DIY approach is the right choice. Add a one-figure characterization pass during bring-up: SLF3S fast-mode flow spectrum without dampener vs. with dampener, showing the ~10× attenuation at the pump fundamental. This becomes a methods-paper deliverable.

### Pump encoder

An AS5600 magnetic angle encoder mounted on the pump shaft provides 14-bit position with I²C readout. ~$10. The encoder serves two purposes:

1. **Closed-loop verification**: confirms the motor is actually rotating at the commanded step rate (catches stalls and lost steps independent of TMC2209 diagnostics).
2. **Phase-locked pulsation analysis**: synchronizes SLF3S flow-rate samples to roller phase for harmonic decomposition (see "Pulsation as covariate" below).
3. **Tubing-creep diagnostic**: encoder-revolutions vs delivered-volume (SLF3S-integrated) ratio drifts when pump tubing wears, separating that failure mode from gap-height drift.

### Closed-loop shear stabilization

The Teensy closes a PID directly on the experimental variable — wall shear stress — via the SLF3S flow reading and the locked channel geometry:

```text
Q_target_ml_min   = target_shear_pa · w · h² / (6 · μ) · 60
Q_measured_ml_min = SLF3S.read_flow()
error             = Q_target_ml_min - Q_measured_ml_min
step_rate_hz      = base_step_rate + Kp · error + Ki · ∫ error dt
```

Closing on flow with a viscosity-aware shear setpoint is cleaner than open-loop pump control because the controller compensates directly for pump tubing creep, gasket compression, and pulsation residual, without having to model any of it. The viscosity assumption is the only modeled term, and it's checked once per chamber against the gas-side differential-pressure rig (see "Validation methodology" / `docs/protocol.md` § "Per-chamber sensor validation").

Loop bandwidth is set by the SLF3S response time (fast-mode sampling at ~100–1000 Hz, plus ~10–30 ms smoothing to reject pulsation harmonics) and the dampener-attenuated pulsation residual. Conservative tuning (Kp ~0.5, Ki ~0.1) gives ±3 % shear stability over multi-hour experiments — uncommon in the bone mechanotransduction literature, where most papers report pre-calibrated pump RPM as ground truth without continuous correction.

The closed loop runs only after a sensor zero check has passed at startup (pump off → Q within ±0.05 mL/min of zero). If the SLF3S faults, the controller reverts to open-loop on the last known good calibration and raises a warning.

### Real-time digital twin

A Hagen-Poiseuille forward model runs in firmware at the same rate as the sensor sampling. Inputs: commanded step rate from the pump controller, calibrated `steps_per_ml` constant, measured T from inline DS18B20, channel geometry from `hardware_config.h`, viscosity lookup `μ(T)` from a small table. Output: predicted ΔP.

```text
Q_predicted = step_rate_hz · 60 / steps_per_ml
ΔP_predicted = 12 · μ(T) · L_taps · Q_predicted / (w · h³)
twin_quality_ratio = ΔP_measured / ΔP_predicted
```

The ratio is a continuous quality indicator. Under correct operation, it sits at 1.00 ± 0.05. Departures surface failure modes:

| Departure | Likely cause |
|---|---|
| Slow ratio drift over hours | Gap-height drift (gasket creep, swelling), or pump tubing creep |
| Sudden ratio anomaly at bubble-transit timescale | Bubble in channel |
| Ratio offset that follows temperature | Viscosity model error or media aging |
| Ratio drops while pump RPM stays steady | Pump slip or chamber leak |
| Ratio rises while pump RPM stays steady | Channel partial blockage |

Without the inline flow sensor, the twin can't separately diagnose pump tubing creep from gap-height drift — both manifest as slow ratio drift. The remedy is the at-bench calibration cadence: a calibration run distinguishes the two by isolating the pump (gravimetric flow check at known RPM) from the chamber (ΔP at known flow with reference fluid). The twin's role downgrades from "diagnostic that pinpoints failure" to "alarm that something has drifted, run calibration day."

The twin runs in firmware and adds one log column (`twin_quality_ratio`) plus a configurable fault threshold. Zero hardware cost.

### LSM 880 timing integration

The shear measurement is only useful if it's time-aligned with the calcium frames. The integration path:

- **Hardware**: the LSM 880 trigger output routes to a Teensy interrupt-capable pin (pin 6 in the existing pin map) via the isolated BNC board the architecture doc already specifies.
- **Firmware**: on each LSM trigger interrupt, log a synthetic event into the sensor stream as `frame_marker, frame_index`, with the same Teensy microsecond timestamp as the surrounding sensor samples.
- **Analysis**: the LSM TIFF/CZI metadata contains the frame number; the Teensy log contains frame markers. Matching them aligns the two clock domains to <1 ms.

This is a five-line firmware change and a single BNC cable, but without it the SLF3S flow-derived shear measurement that grounds all the analyses cannot be tied to the calcium frames it's meant to validate.

### Pulsation as covariate

There is published evidence that osteocyte mechanotransduction is frequency-tuned (Lewis 2017 framework, the Govey/Kwon/Hum/Donahue oscillatory-flow lineage). The spectral content of the shear waveform may matter more than the time-averaged value. The bone literature universally treats peristaltic pulsation as noise to be filtered. Treating it as a structured signal with logged harmonic content is a different framing.

**Implementation**:
1. Synchronize AS5600 encoder timestamp with SLF3S flow-rate samples and LSM 880 frame trigger, all on the Teensy.
2. Phase-bin the flow-rate waveform to roller position over many revolutions.
3. Fourier-decompose to recover pulsation amplitude per harmonic.
4. Log per-experiment: pulsation fundamental amplitude, second-harmonic amplitude, third-harmonic amplitude, total harmonic distortion.
5. In analysis, test whether calcium event probability per cell is modulated by the local pulsation phase or harmonic content.

Whether or not the cells respond to the harmonics, the analysis is publishable: the first time-resolved characterization of peristaltic pulsation as a covariate of osteocyte calcium response.

Required hardware: the SLF3S + AS5600 + dampener pair already specified. The novelty is firmware and analysis, not parts cost.

### Calibration protocol

At-bench calibration day, run before each experimental campaign. Without an inline flow sensor for continuous cross-validation, calibration day is the load-bearing verification step.

1. **Setup**: replace cell-seeded coverslip with a clean blank. Reassemble chamber per torque/hard-stop spec.
2. **Reference fluid**: fill the loop with NIST-traceable glycerol-water mixture at known viscosity. 50:50 v/v glycerol-water at 25 °C is 5.62 mPa·s; viscosity standards traceable to NIST are available from Sigma at $30–50 per set. Use the temperature-corrected viscosity for the actual lab temperature.
3. **Flow sweep**: run pump through five flow setpoints spanning the experimental range (e.g., 5, 20, 50, 100, 200 mL/min).
4. **Gravimetric check at each setpoint**: collect outlet mass on a balance over a fixed interval to derive actual delivered Q. This is the at-bench equivalent of the inline flow sensor's continuous reading. Confirm Q matches commanded setpoint within 5 % across all five points; correct `steps_per_ml` if needed.
5. **Flow check at each setpoint**: confirm the SLF3S Q reading agrees with the gravimetric Q within ±5 % across all five points, and that the shear value derived from SLF3S Q via Hagen-Poiseuille is within 3 % of the analytical shear computed from the glycerol-water properties at the gravimetric Q.
6. **Diagnose**: if SLF3S Q deviates >5 % from gravimetric, investigate sensor zero drift, bubble in the SLF3S channel, or recalibration of the SLF3S factory zero. If gravimetric Q deviates >5 % from commanded, investigate pump tubing wear, motor calibration, or `steps_per_ml` constant. If the derived shear deviates >5 % from analytical at correct Q, investigate gap height (CMM measurement of the chamber after disassembly) or gasket condition.
7. **Save certificate**: store calibration data as part of every experiment's metadata directory. Include date, reference fluid lot, lab temperature, all five setpoint comparisons (commanded, gravimetric, ΔP-derived shear, analytical shear), and pass/fail flags.

This converts the chamber from "we hope it's calibrated" to "we calibrated it Tuesday morning, here's the certificate." A single such protocol page is the difference between a methods chapter and a methods paper. The gravimetric step is the disciplined replacement for an inline flow sensor: less convenient, less continuous, but rigorous when done.

Cost per calibration campaign: $30–50 for reference fluid plus ~30–45 minutes of bench time.

### Sterilization and biocompatibility

| Component | Sterilization method | Notes |
|---|---|---|
| Chamber steel | Autoclave | 316L, electropolished, passivated; standard CIP/SIP compatible |
| FEP/PEEK tubing | Autoclave | Replace per protocol cadence regardless |
| Sensirion SLF3S-1300F (in controller, wetted) | **Not autoclavable.** Clean-in-place per `docs/cleaning_protocol.md`: DI water flush → 1 % Tergazyme → 70 % IPA → sterile DI water rinse. Recirculation through the same pump that drives experiments. | PEEK-wetted; max reagent temperature ~50 °C; no chlorinated solvents; never run dry |
| Validation-rig SEN0343 (LWLP5000) — one-time per chamber, not in deployed device | Wipe housing with 70 % ethanol; sensor is gas-only via standpipes during the validation pass | See `docs/protocol.md` § "Per-chamber sensor validation" |
| Hydrophobic membrane filters (Millex-FG) | Replace per validation campaign | Used during the one-time validation pass between chamber standpipes and the SEN0343; PTFE 0.22 µm, single-use |
| Dampener syringes + membranes | Replace per use | Cheap; do not autoclave the trapped-air compliance assembly |

Recommended workflow: autoclave the chamber + tubing + IDEX fittings as one assembly. Re-attach to the controller-side loop (pump + SLF3S + dampeners) in a hood using sterile fittings; the SLF3S stays with the controller and is cleaned-in-place by recirculation, never exposed to steam. During each chamber's one-time validation pass, the gas-side standpipe stack is attached to the chamber's pressure-tap ports and is autoclavable separately if borosilicate, ethanol-flushed if acrylic; the SEN0343 itself wipes clean with ethanol.

Verify there is no DC ground loop between the LSM 880 stage, the chamber, and the Teensy power supply during bring-up. This has caused mystery noise in published microfluidic-confocal setups even when no sensor is in direct media contact.

### Firmware additions

Pin map additions to `hardware_config.h`:

| Teensy pin | Function | Notes |
|---:|---|---|
| 18 SDA | SLF3S-1300F and AS5600 I²C | Shared bus; sensors use distinct addresses |
| 19 SCL | I²C | |
| (existing) 6 | LSM 880 frame trigger interrupt | Reused from existing trigger IN |

I²C address allocation:
- SLF3S-1300F: 0x08 (default for the SLF3 family on Wire)
- AS5600: 0x36 (default)
- DS18B20 probes: OneWire on pin 20 (existing)

If long I²C runs (>1 m) become necessary between the controller and the chamber-mounted sensors, add a P82B96 I²C buffer/extender or shift to differential UART/RS-485.

New log columns in the CSV log:

```text
flow_ml_min, shear_from_flow_pa, slf3s_temperature_c,
slf3s_flags, twin_quality_ratio, pulsation_fundamental_amplitude_pct,
encoder_position_deg, frame_marker, frame_index,
calibration_certificate_id
```

The `slf3s_temperature_c` column is the SLF3S's reading of the fluid temperature in the sensor channel, free over the same I²C read as the flow measurement. It serves as a media-side thermal sanity check that complements any DS18B20 probes elsewhere in the loop. `slf3s_flags` carries the sensor's onboard signaling word (bubble-detect, etc.).

New fault codes in the `safety` module:

| Fault | Trigger | Action |
|---|---|---|
| `FLOW_SENSOR_FAULT` | SLF3S-1300F communication failure | Pump disable, fault latch |
| `SHEAR_OUT_OF_RANGE` | Measured shear deviates >10 % from setpoint for >5 s while in HOLDING state | Pump disable, fault latch, require reset |
| `TWIN_QUALITY_DEGRADED` | `twin_quality_ratio` outside [0.85, 1.15] for >30 s | Warning, log, continue; recommend calibration day |
| `FLOW_ZERO_OUT_OF_TOL` | SLF3S zero offset >0.1 mL/min drift from last calibration with pump off | Warning at startup; require operator acknowledge |
| `BUBBLE_LIKELY` | SLF3S bubble-detect flag fires OR sharp Q transient outside expected envelope | Log event with timestamp, continue |

New firmware module: `shear_estimator`. Inputs: SLF3S flow + temperature, encoder position, pump command. Outputs: shear estimate, twin quality ratio, pulsation harmonic decomposition. Lives between `sensors` and `protocol_runner` in the existing module split.

### Bench bring-up sequence

Extension to `electronics_bringup_checklist.md`. After steps 1–10 of the existing checklist:

| Step | Test | Pass condition |
|---:|---|---|
| 11 | SLF3S dry / air-purge read | Sensor reads ~0 mL/min with the channel empty and pump off; bubble-detect flag asserts |
| 12 | Loop prime | Reservoir → pump → SLF3S → dampener → chamber loop primed with degassed working medium, no persistent bubbles at the SLF3S inlet |
| 13 | SLF3S wet zero | With pump off and water in loop, SLF3S reads within ±0.05 mL/min of zero after 30 s settle |
| 14 | Encoder sanity | AS5600 returns expected position changes during pump rotation |
| 15 | Calibration day verification | SLF3S Q within ±5 % of gravimetric Q at five setpoints with reference fluid; derived shear within ±3 % of analytical |
| 16 | Pulsation characterization | SLF3S fast-mode spectrum shows expected pump fundamental and harmonics |
| 17 | Dampener characterization | Spectrum with dampeners shows ~10× attenuation at fundamental |
| 18 | Frame-marker time alignment | Synthetic LSM trigger pulses produce frame markers at correct timestamps |
| 19 | Closed-loop shear stabilization | PID holds shear at setpoint within ±3 % over 30-minute hold |
| 20 | Per-chamber validation rig cross-check (one-time per chamber, methods only) | SEN0343 ΔP-derived flow tracks SLF3S Q within ±5 % across the operating range; regression slope 1.00 ± 0.05; certificate filed |

Wet microscope run is gated on steps 1–19 plus the existing wet-run gate in the bring-up checklist.

### Multi-tap pressure profile (future v3)

For a v3 chamber revision, expand the validation rig from two pressure taps to four (e.g., at 5, 20, 35, 45 mm from the inlet), multiplexed to a single differential pressure sensor via four MS5837-30BAs at distinct I²C addresses through a TCA9548A multiplexer.

Why it's worth the v3 complexity:
- **Verifies the fully-developed Poiseuille assumption directly.** If the four pressures fall on a straight line vs. axial position, the channel is in laminar fully-developed flow and τ_w = (dP/dx) · h/2 is rigorous. If they curve at the inlet, you're seeing entrance effects that bias the shear computation.
- **Detects gasket compression drift in situ.** If h drifts non-uniformly along the channel (gasket creep is rarely symmetric), the pressure profile slope changes locally. Two taps cannot see this; four can.
- **Methods-paper contribution.** No published osteocyte chamber does multi-tap pressure profiling in the loop.

Cost: 4× MS5837-30BA at $15 each = $60, plus a TCA9548A multiplexer at $2. Hold for v3.

### µPIV validation rig (future work)

The chamber paper's strongest external reference is a particle image velocimetry station that resolves the parabolic flow profile across the gap. Per Acquah et al. (HardwareX 2024), a complete µPIV system can be built for ~$500: USB3 global-shutter camera (FLIR Blackfly S BFS-U3-04S2M ~$465 or Basler ace2 ~$500), 532 nm laser line generator, 1 µm fluorescent or polystyrene tracer beads, PIVlab/OpenPIV analysis.

The chamber would need a transparent sapphire or fused silica side window for the PIV camera path (the bottom is the cover glass for the LSM 880; a second window in the sidewall is feasible). This is a one-time chamber redesign cost, not a recurring sensor cost.

The µPIV station does not run during every experiment. It periodically validates that the SLF3S flow-derived shear values agree with a true measured velocity profile. This is the strongest independent verification possible at ~$500 and converts the methods paper from "in-loop flow measurement plus per-chamber ΔP cross-calibration plus reference-fluid calibration" to that combination plus direct optical velocity profile validation.

Hold for after v2 validates the dual-sensor stack.

### Methods-paper claims this enables

The bone mechanotransduction literature almost universally reports shear as a calibrated pump RPM with no in-loop verification. This sensor stack supports four claims, each substantive enough for individual mention in a methods paper:

1. **(Strong)** Continuous, in-loop wall shear measurement via inline liquid flow (Sensirion SLF3S-1300F) mapped to shear through the locked Hagen-Poiseuille channel geometry, time-aligned with each LSM 880 frame. First in-loop shear measurement in an osteocyte parallel-plate flow chamber.
2. **(Strong)** Closed-loop shear-stabilized peristaltic perfusion, with the SLF3S as the feedback element controlling pump duty cycle directly on the experimental variable (shear, mapped from measured flow + geometry). Unprecedented in the MLO-Y4 literature.
3. Quantitative logging of peristaltic pulsation as a covariate of calcium-flux response, via the high-bandwidth SLF3S sample stream phase-locked to the AS5600 encoder.
4. **(Strong)** Per-chamber cross-validation against an independent gas-side differential-pressure measurement (DFRobot SEN0343 / All Sensors LWLP5000 + temporary standpipes + Millex-FG separators), giving a calibration figure that grounds every downstream shear value reported.
5. Open-source firmware (Teensyduino), parametric chamber CAD, characterized DIY pulsation dampeners, and per-campaign calibration protocol with NIST-traceable reference fluid plus gravimetric Q verification, releasable under MIT (code) + CC-BY-4.0 (hardware/docs).

### BOM and cost summary

**Deployed device:**

| Item | Source | Cost (USD) |
|---|---|---|
| Sensirion SLF3S-1300F inline liquid flow sensor | Digi-Key / Mouser | $230–280 |
| AS5600 magnetic encoder breakout + magnet | Adafruit / Mouser | $10 |
| 2× IDEX 1/4-28 inlet/outlet fittings (PEEK) | IDEX / Cole-Parmer | $30 |
| 2× DIY dampener syringes (5 mL each) + tee fittings + Millex-FG separator | McMaster / Cole-Parmer | $20 |
| Mounting brackets, cable, JST connectors, pull-ups | already in inventory + ~$10 | $10 |
| **Subtotal — deployed device flow + pulsation stack** | | **$300–360** |
| Calibration day reference fluid (NIST-traceable glycerol-water set) | Sigma | $30–50 per campaign |
| Gravimetric calibration: scale | most labs already have one | $0 |

**Per-chamber validation rig (one-time per chamber, not in deployed BOM):**

| Item | Source | Cost (USD) |
|---|---|---|
| DFRobot SEN0343 (LWLP5000 ±500 Pa diff pressure, I²C) | DFRobot / Digi-Key | $50–65 |
| Raspberry Pi Pico 2 with headers | Adafruit / Mouser | $5 |
| Half-size breadboard + jumper wires | generic | $5 |
| 2× standpipes (borosilicate or acrylic, 6 mm × 50 mm + tee fittings) | McMaster / Sigma | $20 |
| 2× hydrophobic 0.22 µm membrane filters (Millex-FG) — gas-side barriers | Sigma / Fisher | $15 |
| 1/16″ ID silicone tubing + luer-to-barb adapters | Cole-Parmer | $15 |
| **Subtotal — validation rig** | | **$110–125** |

The validation rig is amortized across every chamber built; one rig in the lab serves all subsequent chamber bring-ups.

### Open questions before purchase

- Verify the SLF3S-1300F's ±26 mL/min full-scale range is right for the operating window. For 0.5–10 Pa shear over the locked 24 mm × 0.25 mm channel, required Q runs ~8 to ~167 mL/min — comfortably inside the SLF3S full-scale. If the experimental window expands above ~10 Pa shear routinely, evaluate the SLF3S-4000B (wider range, similar architecture).
- Confirm chamber steel can accept two optional pressure-tap bores for the one-time validation rig without compromising the cover-glass pocket geometry. The bores are plugged during routine experiments; they only need to be present for the validation pass. The pressure taps go through the top steel ceiling, well clear of the channel-floor optical region.
- Confirm DC ground-loop isolation between LSM 880 stage, chamber metal, controller power supply, and Teensy ground during the bench bring-up before the first wet microscope run.
- Decide on the at-bench gravimetric calibration cadence. Recommended: quarterly full calibration + daily SLF3S zero-check at the pre-experiment prime (see `docs/cleaning_protocol.md` § "Pre-experiment prime").

### Recommendation

Lock the SLF3S-1300F as the deployed in-loop flow sensor with closed-loop shear control via Hagen-Poiseuille geometry mapping (~$300–360 in deployed-device parts). Build the DIY dampeners during electronics bring-up alongside the existing checklist. Run the at-bench calibration protocol with NIST-traceable reference fluid plus gravimetric Q verification before the first cell experiment, and at a defensible cadence thereafter (recommended: quarterly full calibration + daily SLF3S zero check).

Once per chamber, run the validation pass against the bench-side gas-side ΔP rig (~$110–125 in shared lab inventory, amortized across all chambers built). The resulting cross-calibration figure backs the methods-paper claim that the in-loop SLF3S measurement is independently grounded.

Multi-tap pressure profiling and µPIV validation remain v3 and methods-paper-supporting work respectively. None of those gate the v2 build.

---

## Electronics Bring-Up Checklist

Use this as the bench sequence before anything goes near the microscope. The goal is to build confidence one subsystem at a time and avoid debugging wet fluidics, motor noise, firmware, and microscope triggering all at once.

Primary architecture doc: `electronics_controller_architecture.md`.

### Immediate Milestone

Build a Teensy-controlled pump driver that can:

- receive a flow setpoint over USB serial;
- generate stable STEP pulses with a hardware timer;
- enable/disable the TMC2209 safely;
- show state on the OLED;
- write a CSV timing log to microSD.

This is the first electronics milestone. Sensors, GUI, and microscope trigger build on top of it.

### Hard Rules

- Do not connect anything to the i880 until the isolated BNC trigger board is bench-tested.
- Do not run wet fluidics on a solderless breadboard.
- Do not drive any Teensy pin above 3.3 V.
- Do not power the TMC2209 motor rail without local bulk capacitance and a fuse.
- Do not treat ESP32 wireless control as part of the real-time or safety path.
- Do not leave TMC2209 `ENABLE` floating; it should default disabled on boot/reset.

### Bench Setup

| Step | Test | Pass condition |
|---:|---|---|
| 1 | Teensy USB serial | `PING` command returns known response |
| 2 | microSD logging | Creates file, writes header, appends timestamped rows |
| 3 | OLED | Displays boot state and dummy setpoint |
| 4 | Encoder/button | Changes dummy setpoint and enters/clears menu state |
| 5 | TMC UART | Driver responds to status/config readback |
| 6 | STEP pulse output | Logic analyzer confirms requested frequency |
| 7 | Motor rotation | Direction and enable polarity confirmed at low current |
| 8 | DS18B20 bus | All probes read and IDs are mapped to labels |
| 9 | Trigger board bench test | No continuity between Teensy ground and BNC shield; pulse visible on both sides |
| 10 | Full dry protocol | Baseline/ramp/hold/ramp-down sequence logged correctly |
| 11 | Off-microscope water loop | Flow calibration verified; visual leak inspection at fittings and chamber-to-cover-glass interface |

### Suggested First Wiring Map

| Subsystem | Teensy pins |
|---|---|
| TMC2209 UART | 0 RX1, 1 TX1 |
| TMC2209 STEP/DIR/ENABLE | 2, 3, 4 |
| Isolated trigger OUT/IN | 5, 6 |
| OLED SPI | 8 RST, 9 DC, 10 CS, 11 MOSI, 13 SCK |
| OneWire temperature | 20 with 4.7k pull-up to 3.3 V |
| Encoder | 24, 25, 26 |

Move any pin only once, then update `hardware_config.h` and `electronics_controller_architecture.md`.

### Missing Parts To Buy Or Confirm

Minimum to finish a microscope-safe controller:

- 24 V DC supply sized for the pump and driver.
- Confirmed pump model, motor connector, and tubing size.
- TMC2209 heatsinks and mounting plan.
- Panel-mount BNC connector or BNC pigtail for the isolated trigger board.
- Optocouplers or digital isolators for trigger IN/OUT.
- Resistor values beyond the current 4.7k stock: 220, 330, 1k, 2.2k, 10k, 100k.
- Perfboard or a small custom PCB; breadboard is for bench proof only.
- Enclosure, cable glands, strain reliefs, terminal blocks, and labels.
- Latching motor-power switch or E-stop.

Optional but useful:

- small piezo buzzer or panel alarm LED;
- 24 V TVS diode and additional bulk capacitors near TMC VM/GND;
- USB panel feedthrough;
- shielded cable for trigger and low-level sensor wiring.

### Pump Calibration

Do not use the pump catalog curve as the paper-grade flow calibration.

Procedure:

1. Assemble pump tubing and water loop off-microscope.
2. Run the pump at several STEP frequencies for a fixed time.
3. Collect outlet mass on a scale.
4. Convert mass to volume using water density or media density if known.
5. Fit:

```text
flow_ml_min = slope * step_rate_hz + intercept
```

6. Store the inverse calibration in firmware:

```text
step_rate_hz = (target_flow_ml_min - intercept) / slope
```

7. Repeat after changing pump tubing, tubing compression, pump head, or temperature range.

### Microscope Trigger Validation

Before connection to the actual i880:

- confirm whether the core has the optional trigger/user interface box installed;
- confirm whether ZEN expects rising edge, falling edge, level, or marker mode;
- verify acceptable pulse width with core staff;
- measure the isolated trigger board output with no continuity to Teensy ground;
- bring only the trigger board and controller to the microscope first, with no fluidics attached.

The first microscope electronics test should be a marker/trigger test only.

### Wet Run Gate

A wet run on the microscope is allowed only after:

- pump motion works off-microscope;
- the controller is in an enclosure;
- the 24 V rail is fused;
- all wires are strain relieved;
- the isolated trigger board has been validated;
- the water loop has run for at least 30 minutes off-microscope with no observed leaks at any fitting or seal;
- flow calibration has been recorded.

### First Firmware File Set

Recommended first repo scaffold:

```text
firmware/
  platformio.ini
  src/
    main.cpp
    hardware_config.h
    pump_control.h
    pump_control.cpp
    logger.h
    logger.cpp
    display_ui.h
    display_ui.cpp
    serial_commands.h
    serial_commands.cpp
```

Keep firmware boring at first. A reliable step pulse and a trustworthy log are more important than a polished GUI.

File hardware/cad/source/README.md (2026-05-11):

# Fusion Model Seed

This folder starts the clean Fusion 360 path for the v2 flow chamber.

## Current File

- `flow_chamber_v2_seed.py` creates a new Fusion design with the locked geometry parameters and one physical body: the CG15KH1 cover glass.

## Seed Philosophy

The cover glass is the first fixed object. Everything else should be designed around it.

Coordinate convention:

- `X`: flow direction / 50 mm cover-glass length
- `Y`: 24 mm cover-glass width
- `Z`: optical stack height
- `Z = 0`: fluid-facing cell surface of the cover glass
- `Z = -cover_glass_t`: objective-facing bottom surface of the cover glass

## What It Creates

- User parameters for the locked v2 geometry:
  - cover glass, pocket, channel, gasket, hard-stop, body envelope, objective clearance, port, and M3 reference dimensions
- One body:
  - `CG15KH1_24x50x0p170_cover_glass`

It does not create chamber body blanks, channel reference solids, gasket bars, port cylinders, hard-stop pads, or objective envelopes.

## How To Run

1. Open Autodesk Fusion 360.
2. Open `Scripts and Add-Ins`.
3. Run `flow_chamber_v2_seed.py`.
4. Save the generated design as the first native Fusion model.

## First Manual Modeling Move

Start from the cover-glass top face as the channel floor datum. Add the flow-channel sketch and glass pocket/support geometry around that body, using the script-created user parameters rather than typed one-off dimensions.

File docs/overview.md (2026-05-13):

# Overview

## What this is

An open-source parametric parallel-plate perfusion flow chamber for delivering programmable wall-shear-stress waveforms to MLO-Y4 osteocyte-like cells on a Zeiss LSM 880 inverted multiphoton microscope. The system covers hardware (CAD, BOM, machined parts), firmware (Teensy 4.1 + TMC2209 + isolated trigger), and an Electron operator app with a synth-style control surface.

## Who it's for

- **Wet-lab biologists** who want to apply controlled, programmable shear stress to adherent cells on an inverted microscope without writing motor-control code.
- **Replicators** building a similar chamber for osteocyte mechanotransduction, endothelial flow studies, or any parallel-plate adherent-cell shear assay in the 0.5 – 10 Pa range.
- **Method developers** extending the open-source platform — adding new sensors, new waveform protocols, multi-chamber operation, or different cell models.

## What the paper shows

Headline claims (filled in on publication):

1. **Continuous, in-loop wall shear measurement** via inline liquid flow (Sensirion SLF3S-1300F), time-aligned with each microscope frame. First in-loop shear measurement in an osteocyte parallel-plate flow chamber.
2. **Closed-loop shear-stabilized peristaltic perfusion** — the SLF3S inline flow sensor is the feedback element controlling pump duty cycle directly on the experimental variable (shear, mapped from flow via Hagen-Poiseuille geometry). Unprecedented in the MLO-Y4 literature.
3. **Quantitative logging of peristaltic pulsation as a covariate** of calcium-flux response, via the high-bandwidth SLF3S sample stream phase-locked to the pump-shaft encoder.
4. **Cross-validated shear measurement.** Each chamber is characterized once before deployment against an independent differential-pressure measurement (gas-side standpipes + DFRobot SEN0343 / LWLP5000), giving a per-chamber calibration figure published in the methods.
5. **End-to-end open-source release** — parametric CAD, machinable STEP, deterministic firmware, operator app, calibration protocol — all under MIT (code) + CC-BY-4.0 (hardware/docs).

See the paper (TBD on publication) for the experimental dataset and quantitative results.

## How the docs are organized

| Doc | When you need it |
|---|---|
| `docs/theory.md` | The science — channel geometry, shear math, parameter family, materials |
| `docs/architecture.md` | The system — modules, microscope constraint, seal architecture, parametric CAD spec |
| `docs/protocol.md` | The wet-lab procedure — cell culture, dye loading, chamber setup, stimulus, imaging |
| `docs/design_language.md` | The aesthetic — hardware (TX-6 influence) and software (Drams/Rams) |
| `docs/reproducing.md` | The recipe — regenerate a paper figure end-to-end |
| `hardware/` | BOM, assembly, machining notes, CAD, drawings, electronics |
| `firmware/` | PlatformIO project for the Teensy controller |
| `app/` | The Electron operator app |
| `examples/demo_study/` | A sample folder-based study showing the on-disk format |

## Locked technical decisions

These are not negotiable within this paper's scope. Future revisions may revisit them; the current paper measurements are taken with these locked.

| Decision | Locked value |
|---|---|
| Cell line | MLO-Y4 osteocyte-like |
| Microscope | Zeiss LSM 880 inverted (confocal/multiphoton) |
| Reference objective | 40×/1.2 W (water, 0.28 mm WD) |
| Channel | 24 mm × 50 mm × 0.25 mm parallel-plate |
| Cover glass | Thorlabs CG15KH1 #1.5H |
| Pump | Kamoer KCS peristaltic, low-pulsation |
| Controller | Teensy 4.1 + TMC2209 |
| Body material | 316L stainless, electropolished + passivated |
| Sealing | Medical-grade neutral-cure silicone only — **no RTV / no acetoxy** |

Working fluid: α-MEM with serum at 37 °C, μ ≈ 0.9 mPa·s.

Operating shear range: 0.5 – 10 Pa. Operating flow range: ~10 – 200 mL/min through the canonical channel.

## What this project is NOT

- **Not** a long-term bioreactor (no week-long perfusion experiments without separate engineering).
- **Not** a production medical device (no FDA / CE pathway).
- **Not** a microfluidic platform — this is a macro-scale chamber, intentionally compatible with standard wet-lab workflows.

See `CLAUDE.md` for full agent / contributor conventions.

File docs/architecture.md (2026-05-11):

# Architecture

> Migrated from `design_spec_v2.md` in the dev archive (architecture/system portions). Theory and channel geometry are in `docs/theory.md`. Industrial design language is in `docs/design_language.md`. The full electronics architecture and bench bring-up sequence are consolidated in `hardware/electronics/README.md`. Vendor-facing machining notes are in `hardware/machining_notes.md`.

## System architecture

The reference system is modular:

| Module | Default choice | Reason |
|---|---|---|
| Reusable precision chamber | 316L stainless steel | stiff, machinable, cleanable, durable |
| Optical cell substrate | #1.5 borosilicate cover glass | microscope-compatible, cheap, standard |
| Experimental substrate | titanium, polymer, hydrogel, ECM, ceramic, or coated glass insert | keeps biology customizable |
| Fluidic consumables | FEP/PTFE tubing, silicone pump tubing, replaceable gasket | low cost, replaceable, accessible |
| Controller | Teensy 4.1 | deterministic pump timing, logging, trigger sync |

## Microscope constraint

The chamber is for a Zeiss LSM 880 inverted microscope.

Relevant objectives:

| Objective | Working distance | Use |
|---|---:|---|
| 10x/0.3 air | 5.2 mm | setup and locating |
| 20x/0.5 air | 2.0 mm | forgiving calcium/flow validation |
| 32x/0.85 water | 1.1 mm | long-WD higher-resolution option |
| 40x/1.2 water | 0.28 mm | primary high-NA live-cell design constraint |
| 63x/1.4 oil | 0.19 mm | Airyscan / endpoint morphology only |

Design implication: the objective-facing underside must expose the #1.5 cover glass directly in the imaging zone. No steel, gasket, screw head, retaining lip, or port boss should enter the objective clearance envelope.

Use the third-party scope-holder reference STEP at `hardware/cad/components/scope_holder.stp` as the current measured holder/objective reference for collision checks. This reference is caliper-derived and should get clearance margin, not a zero-clearance fit.

## Titanium experiment geometry

The target microscope is inverted, so opaque titanium coupons require a specific strategy. Do not assume cells on opaque metal can be imaged from below through the metal.

Acceptable strategies:

1. **Titanium-modified transparent glass floor**
   - Best for i880 high-NA live calcium imaging.
   - Examples: sputtered titanium or titanium-alloy films, thin oxide coatings, patterned/topographic transparent-compatible coatings.
   - Weakness: less implant-faithful than bulk machined/etched coupons.

2. **Opaque titanium ceiling insert**
   - Cells are cultured on titanium, then the coupon is mounted as the channel ceiling with cells facing downward into the channel.
   - Objective images from below through cover glass and media.
   - Requires long-working-distance objectives and careful channel height/focus validation.
   - This is not compatible with the 40x/1.2 water objective if the focal plane is too far above the coverslip.

3. **Alternate imaging geometry**
   - Use an upright microscope, side imaging, or another microscope if true bulk opaque coupons must be imaged from the cell side.

Decision required before final CAD: is titanium a transparent floor coating, an opaque ceiling insert, or outside this chamber's live-imaging mode?

## Seal architecture

Hard requirement: channel height and seal compression must be controlled by geometry, not by screw torque.

Current prototype architecture:

- piston/radial O-ring seal between the top flow plate and bottom plate;
- steel-to-steel hard-stop contact between top and bottom plates;
- channel height set by the machined pocket/boss/glass-thickness stack, not by O-ring compression;
- actual channel height to be empirically calibrated after machining and assembly.

Acceptable alternates if prototype leakage or repeatability fails:

1. machined channel height plus perimeter gasket/O-ring seal outside the channel;
2. laser-cut gasket defining channel height, compressed against hard stops;
3. precision spacer/shim defining channel height, with a separate perimeter seal.

Do not combine gasket thickness, O-ring squeeze, glass bending, and screw torque into an uncontrolled height stack.

## Port standard

Prototype port architecture:

- top-mounted luer sockets over the cover-glass / channel region;
- luer-lock plugs for sealed/transport mode;
- luer-to-tubing adapters for pump-loop mode;
- luer-to-vent-cap standpipe adapter for incubator culture-mode experiments if needed;
- smooth/tapered transition into the rectangular channel;
- no dead pockets or bubble traps.

Preferred luer-to-channel transition:

- avoid a vertical luer bore dumping directly into the 0.25 mm channel if packaging allows;
- use a shallow end manifold at each channel end, fully inside the sealed wetted region;
- reference manifold dimensions: about 3-5 mm long, 5-7 mm wide, 0.5-1.0 mm deep, tapering / filleting into the 24 mm × 0.25 mm channel cross-section;
- simplest vertical-bore-to-channel transition is acceptable for the first prototype if cost or machinability is prioritized, but it is expected to be worse for bubble clearing and flow distribution.

The on-hand 1/8 inch ID × 1/4 inch OD silicone tubing should not define chamber port geometry. Use it for external low-pressure loop sections only if useful.

## Fusion parameter set

Use these names in Fusion user parameters. Values are prototype nominal values unless marked as measured/reference.

| Parameter | Value | Purpose |
|---|---:|---|
| `cover_glass_l` | 50.0 mm | CG15KH1 nominal cover glass length |
| `cover_glass_w` | 24.0 mm | CG15KH1 nominal cover glass width |
| `cover_glass_t` | 0.170 mm | CG15KH1 nominal cover glass thickness |
| `cover_glass_xy_tol` | 0.2 mm | Manufacturer length / width tolerance |
| `cover_glass_t_tol` | 0.005 mm | Manufacturer thickness tolerance |
| `cover_glass_pocket_l` | 50.8 mm | Prototype pocket length for sterile drop-in placement |
| `cover_glass_pocket_w` | 24.8 mm | Prototype pocket width for sterile drop-in placement |
| `cover_glass_pocket_corner_r` | 0.5 mm | Pocket internal corner radius |
| `cover_glass_pocket_chamfer` | 0.25 mm | Small lead-in chamfer for easier coverslip placement |
| `channel_l` | 50.0 mm | Locked active channel length (matches full cover-glass length) |
| `channel_w` | 24.0 mm | Locked parallel-plate channel width (matches full cover-glass width) |
| `channel_h` | 0.25 mm | Locked channel height (hard-stop controlled) |
| `imaging_w` | 3.0 mm | Preferred central near-uniform shear imaging width |
| `developed_entry_l` | 1.0 mm | Analytical entrance length is well under 1 mm at canonical Re; whole channel is fully developed |
| `manifold_l` | 4.0 mm | Nominal shallow end-manifold length at each luer bore |
| `manifold_w` | 6.0 mm | Nominal shallow end-manifold width |
| `manifold_h` | 0.75 mm | Nominal shallow end-manifold depth before the thin channel |
| `manifold_transition_l` | 4.0 mm | Nominal taper / fillet transition into the 24 mm × 0.25 mm channel |
| `cover_glass_t_measured` | `cover_glass_t` | Replace with measured lot thickness when available |
| `boss_stack_depth` | `cover_glass_t_measured + channel_h` | Pocket / boss Z stack from glass support datum to channel ceiling |
| `o_ring_gland_clearance` | 0.0 mm | Placeholder until O-ring cross-section and gland are chosen |
| `seal_land_min_w` | 2.0 mm | Initial minimum seal/support land width around flow path |
| `body_l` | 80.0 mm | Initial reusable chamber body length envelope |
| `body_w` | 52.0 mm | Initial reusable chamber body width envelope |
| `body_t` | 12.0 mm | Initial reusable chamber body thickness envelope |
| `bottom_lip_t` | 0.75 mm | Minimum vertical thickness for objective-side glass support lip |
| `objective_window_l` | 46.0 mm | Initial objective-side opening length |
| `objective_window_w` | 23.0 mm | Initial objective-side opening width |
| `objective_ref_d` | 18.8629 mm | Measured objective / nose reference diameter |
| `objective_ref_h` | 45.0877 mm | Measured objective / nose reference height |
| `objective_clearance_radial` | 2.0 mm | Minimum radial clearance around measured objective reference |
| `objective_envelope_d` | `objective_ref_d + 2 * objective_clearance_radial` | Objective clearance envelope diameter |
| `holder_plate_l` | 175.0652 mm | Measured holder plate reference envelope length |
| `holder_plate_w` | 105.1809 mm | Measured holder plate reference envelope width |
| `holder_plate_t` | 5.0 mm | Measured holder plate reference envelope thickness |
| `luer_bore_d` | 2.0 mm | Nominal luer bore into end manifold; verify against vendor STEP |
| `luer_socket_clearance_d` | 16.0 mm | Initial keep-out diameter around top-mounted luer socket / plug |
| `luer_socket_spacing_min` | 20.0 mm | Initial minimum center spacing for finger access |
| `tube_od` | 1.5875 mm | 1/16 inch OD tubing after luer adapter |
| `m3_clearance_d` | 3.4 mm | Reference M3 clearance hole |
| `m3_head_clearance_d` | 5.8 mm | Reference M3 socket-head clearance diameter |
| `m3_thread_pilot_d` | 2.5 mm | Reference M3 tapped pilot diameter |
| `fastener_to_glass_edge_min` | 3.0 mm | Initial minimum fastener clearance from glass edge |
| `tool_clearance_near_objective` | 5.0 mm | Minimum clearance around fittings / screw heads near objective zone |

The seed script that creates these parameters in Fusion is at `hardware/cad/source/flow_chamber_v2_seed.py`.

## Culture plate / sample handling

The open-source system should include a dedicated sample culture holder or well plate.

Requirements:

- holds 24 × 50 mm cover glass or matched inserts repeatably;
- minimizes media volume;
- allows collagen coating and cell culture before chamber assembly;
- keeps samples sterile during transport;
- protects fragile cover glass;
- can support parallel conditions for material/topology experiments.

Recommended material:

- machined polycarbonate for holder / well-plate body if reused and cleaned gently;
- commercial TCPS for routine expansion culture;
- COC/COP if scaling toward disposable optical consumables.

## Controller and instrumentation essentials

Detailed controller architecture, the differential-pressure shear-verification system, and the bench bring-up sequence are all in `hardware/electronics/README.md`.

Primary controller: Teensy 4.1.

Required functions:

- deterministic pump control;
- ramped flow onset / offset;
- SD logging;
- temperature logging;
- microscope timing synchronization if facility trigger I/O is confirmed;
- timestamp authority on the microcontroller, not the laptop.

Important unresolved item: the local i880 guides do not document electrical trigger / BNC behavior. Confirm the exact facility trigger I/O before finalizing the trigger circuit.

## Validation plan

Engineering validation:

- leak test at maximum planned flow;
- gravimetric pump calibration;
- pulsation characterization with and without dampener;
- bubble-trap validation;
- channel-height inspection or flow-based shear validation;
- objective clearance validation on the i880 stage.

Biology validation:

- live/dead assay on glass and substrate variants;
- baseline Fura Red stability with no flow;
- 0.5, 1.0, 1.5, 3.0 Pa shear-response ladder;
- responding-cell fraction and calcium event metrics;
- repeated cleaning / autoclave / passivation compatibility screen;
- optional stainless control to prove chamber material is not driving the signal.

## Do not machine until

- cover glass pocket matches the Thorlabs CG15KH1 reference and later physical glass lot;
- titanium live-imaging geometry is chosen;
- channel width and height are locked;
- seal architecture is locked;
- objective clearance envelope is drawn;
- port standard is locked;
- separate STEP files and PDF drawings exist for each machined part.

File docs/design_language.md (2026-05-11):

# Design language

> Hardware aesthetic (TX-6-influenced precision instrument) carried over verbatim from `design_language_tx6.md` in the dev archive. Software aesthetic section (Drams/Rams visual language for the Electron operator app) is a **placeholder** to author from the live reference at `drams.framer.website` once the app implementation begins.

The flow chamber project has two visually-related but functionally-distinct design languages:

- **Hardware** — the machined chamber, controller enclosure, and culture-handling kit. Reference: Teenage Engineering TX-6 (satin metal slab, sparse warm orange accent, monochrome restraint).
- **Software** — the Electron operator app that drives the controller. Reference: the Drams/Rams visual system at `drams.framer.website` (sibling to TX-6; monochrome surfaces, generous whitespace, sparse orange for active/critical state, no decorative ornament).

Both systems share the same restraint, the same orange accent role, and the same "precision instrument, not consumer gadget" posture.

---

## Hardware aesthetic — TX-6-influenced precision instrument

This section defines the industrial design language for the flow chamber hardware. The primary reference is the Teenage Engineering TX-6, translated into a sterile, open-source biomedical instrument. It is an influence document, not permission to copy Teenage Engineering marks, exact layouts, or product trade dress.

Functional constraints outrank appearance:

- sterility and cleanability;
- optical clearance on the Zeiss LSM 880;
- seal reliability and channel-height control;
- machining cost and accessibility;
- clear assembly by a biology or undergraduate engineering lab.

### Local references

Reference images are at `docs/references/tx6_design_language/images/`. Use `tx6_reference_contact_sheet.jpg` for a quick visual scan. Source links and per-image notes are in `docs/references/tx6_design_language/source_manifest.md`.

The back-side leather/textile/bag language is explicitly out of scope. Those images are only useful for proportion, modular kit presentation, edge treatment, and compact system organization.

### Core impression

The chamber should read as a compact precision instrument, not a disposable lab jig and not a consumer gadget.

Target feel:

- small machined slab;
- dense but orderly functional layout;
- satin metal body;
- crisp black voids where the object opens into ports, slots, windows, or display areas;
- sparse warm orange used only as an active-state or critical-action accent;
- exposed precision hardware where touch or serviceability matters;
- quiet labels engraved or laser-marked directly onto the part;
- no decorative complexity that adds cleaning burden.

### Translation principles

| TX-6 cue | Flow chamber translation |
|---|---|
| Satin aluminum slab | Satin 316L stainless chamber body and clamp, with electropolished/passivated wetted surfaces |
| Tight grid of controls | Orthogonal grid for ports, fasteners, labels, and sensor/control elements |
| Small high-contrast display | Small OLED/status window on the controller, not on the sterile chamber body |
| Black fader slots and jack openings | Dark optical window, port openings, gasket shadows, and display recesses |
| Knurled metal adapter | External thumb screws, port plugs, and removable fittings can be knurled metal |
| Sparse orange controls | Orange only for flow active, prime/purge, emergency stop, or direction indicators |
| Low, compact side profile | Chamber must be low-profile around the objective and stage envelope |
| Precise packaging/system presentation | Culture holders and accessories should pack as a clean modular kit |

### Chamber body rules

- Main body and clamp should be simple rounded rectangles or rectilinear slabs with small corner radii.
- Exterior edges should have consistent shallow chamfers or radii. Do not round sealing lips unless the drawing explicitly calls it out.
- Fasteners should be counterbored, flush, or visually organized. Avoid random exposed screw clutter.
- The cover-glass window should be visually centered and treated as the main functional aperture.
- Ports should align to the channel centerline and use compact labels near the ports.
- The body may have a small serial/QR/data strip on a non-wetted side face or underside.
- Do not add cosmetic grooves, texture, pockets, or engraving on wetted surfaces, seal lands, gasket seats, or glass support surfaces.

### Controller rules

- A small OLED, one primary rotary encoder, and a few tactile buttons are enough.
- Use a quiet orthogonal layout: display top/right, encoder or main control adjacent, status/action buttons grouped below.
- Orange is reserved for flow active, recording/logging, or safety-critical control.
- Labels should be small and direct: `flow`, `prime`, `stop`, `temp`, `log`, `sync`.
- Avoid large explanatory text on the device. The device should be self-evident through layout and labels.

### Culture holder and kit rules

- The culture/sample holder should feel like a precision accessory tray, not a plate hacked into a chamber.
- Use clear, frosted, white, or light gray polymer where biology visibility matters.
- If a transport/storage box is designed, use a molded-tray logic: exact recesses, finger reliefs, protected glass, and labeled positions.
- No leather, textile, foam, porous grips, or soft decorative materials in the cell-culture path.

### Materials and finishes

| Element | Preferred design finish |
|---|---|
| Reusable chamber body | 316L stainless, satin exterior, electropolished/passivated wetted surfaces |
| Clamp / retainer | 316L stainless or anodized aluminum if non-wetted and isolated |
| Controller enclosure | clear / silver anodized aluminum or light gray machined polymer |
| Culture / sample holder | clear / frosted polycarbonate, COC/COP, or white autoclavable polymer where appropriate |
| External fittings | stainless or PEEK/ETFE, visually compact and aligned |
| Tubing | clear FEP/PTFE at chamber, black/neutral external cable-style routing if useful |
| Accent color | small orange marks only; never a dominant theme |

### Prohibited moves

- Do not use Teenage Engineering logos, `TX-6` marks, or exact copied graphic layouts on this device.
- Do not use leather, PU leather, textile, or porous decorative materials.
- Do not style wetted or cleanable areas with ornamental knurling, grooves, stippling, or unnecessary recesses.
- Do not let industrial design invade the optical clearance envelope.
- Do not make the chamber look like a consumer audio device if the geometry no longer serves microscopy, sealing, or sterile assembly.
- Do not use large branding, bright color palettes, or oversized rounded consumer controls.

### Vendor-CAD implications

For the steel parts we send out:

- use a restrained satin-metal exterior with explicit passivation/electropolish notes where relevant;
- keep all visible radii / chamfers consistent across body and clamp;
- make the underside objective window clean and unobstructed;
- align port centerlines, screw patterns, and labels on a simple grid;
- reserve knurled hardware for removable external handling only;
- include no purely decorative machining operations that increase cost or cleaning risk.

### Acceptance check

Before sending CAD:

- The chamber should look like a compact precision instrument from the first render.
- Every visible detail should have a mechanical, optical, assembly, or labeling role.
- Cleaning and cell-culture handling should be simpler because of the design, not harder.
- The device should evoke TX-6 restraint, density, and material confidence without copying its product identity.

---

## Software aesthetic — Drams/Rams visual language

> **Placeholder.** This section is to be authored once the Electron operator app implementation begins. Source: `drams.framer.website` — a sibling visual system to TX-6, applied to a software surface. The following bullets capture the intended principles; the live reference is the source of truth.

Intended principles (subject to confirmation against the live reference):

- Monochrome surfaces (deep neutrals, near-black to off-white);
- Generous whitespace; dense functional layout in the working zones, breathing room around them;
- Sparse warm orange (`accent`) used only for active-state, critical-action, or "live data" cues — never as a dominant color;
- No decorative ornament: gradients, drop shadows, colored backgrounds, illustrative iconography are all minimized;
- Restrained typography: a single neutral typeface with a constrained weight palette; numerical readouts in monospace;
- Synth-style metaphor in the operator UI: control panel divides into named blocks (OSC / SHEAR / ENV / DISPLAY / SYNC / TRANSPORT / MASTER) that mirror Korg Minilogue groupings;
- Custom widgets read as physical instrument controls: knobs (SVG/Canvas + `motion` for inertia), waveform selectors, 7-segment readouts, the rotating wheel.

To author when starting `app/`:

1. Pull the Figma file at `https://www.figma.com/design/J3aZzdLaJmidPQcOxphPdE/flow_chamber?node-id=2004-140` (file key `J3aZzdLaJmidPQcOxphPdE`, root frame node `2004-140`) via the Figma MCP.
2. Use `get_variable_defs` to extract design tokens; write to `app/src/styles/globals.css`.
3. Use `get_design_context` for node `2004-140` and adjacent frames to seed the component palette.
4. Capture per-component principles (knob anatomy, readout typography, panel block divisions, accent-color triggers) here in this section, replacing this placeholder.
5. Cross-reference TX-6 hardware language above where the same rule applies to both surfaces (orange semantics, monochrome restraint, instrument-not-gadget posture).

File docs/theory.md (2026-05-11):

# Theory

> Migrated from `design_spec_v2.md` in the dev archive (theory portions). Architecture/system sections moved to `docs/architecture.md`. Industrial design language moved to `docs/design_language.md`. Cited references for the wet-lab protocol live in `docs/protocol.md`.

## Scientific target

A modular, open-source, live-cell flow chamber that applies well-defined laminar fluid shear stress while imaging osteocyte calcium signaling in real time.

Primary biological models:

- MLO-Y4 osteocyte-like cells.
- IDG-SW3 osteocyte-lineage cells.
- General adherent cell lines with substrate-specific adaptation.

Primary readouts, aligned with Lewis 2017:

- fraction of responding cells;
- activation latency after flow onset;
- calcium peak magnitude;
- decay/recovery time;
- calcium area under curve;
- event frequency / oscillation behavior;
- threshold curves across shear stress and substrate conditions.

## Optical and substrate geometry

Default substrate:

- Thorlabs CG15KH1 #1.5H cover glass reference.
- Material: Schott D263 M.
- Nominal size: 24.0 × 50.0 mm.
- Dimensional tolerance: ± 0.2 mm.
- Nominal thickness: 0.170 mm.
- Thickness tolerance: ± 0.005 mm.
- Prototype CAD pocket target before physical measurement: 50.8 mm long × 24.8 mm wide with 0.5 mm internal corner radii.
- Rationale: the cell-covered cover glass should drop into the pocket without scraping, prying, or tight sterile handling; exact XY registration is less important than gentle placement.

Default biology orientation:

- cells grow on the fluid-facing side of the cover glass;
- cover glass forms the optical floor of the channel;
- objective images from below through the cover glass.

This is the easiest geometry for high-NA live calcium imaging.
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

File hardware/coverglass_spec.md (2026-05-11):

# Cover Glass Procurement Spec

Source drawing: `C:/Users/alex/Downloads/coverglass_drawing_ttn140107-e0w.pdf`

Reference part:

- Manufacturer: Thorlabs
- Item: `CG15KH1`
- Name: Cover Glass #1.5H, 24 x 50 mm
- Material: Schott D263 M
- Sold in packs of 100
- Approximate weight: 0.51 g each

## Drawing Values
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

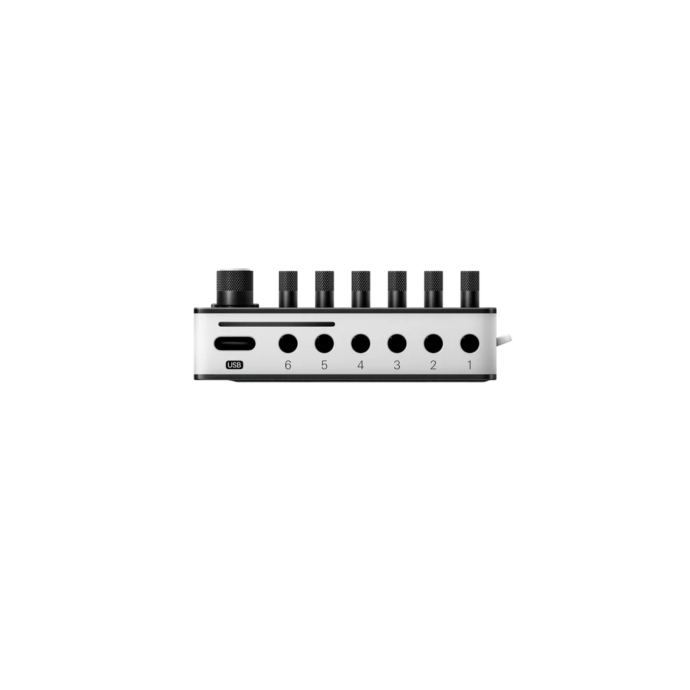
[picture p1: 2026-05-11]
docs/references/tx6_design_language/images/04_tx6_top_inputs_usb_side.webp

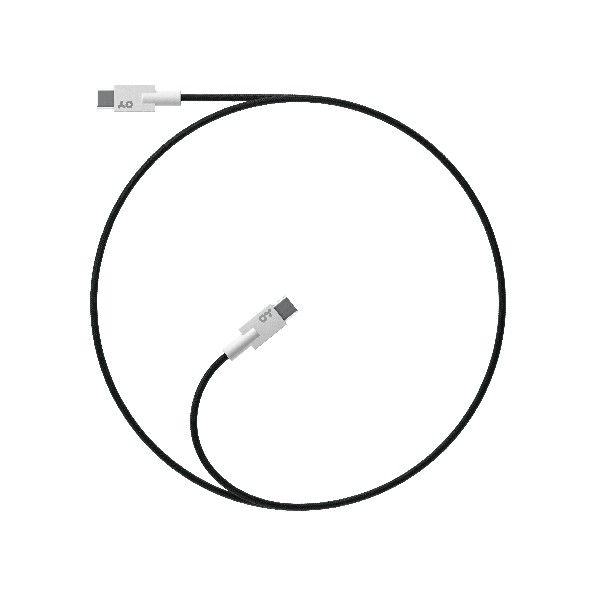
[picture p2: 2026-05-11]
docs/references/tx6_design_language/images/08_tx6_usb_c_cable_black_braid.webp

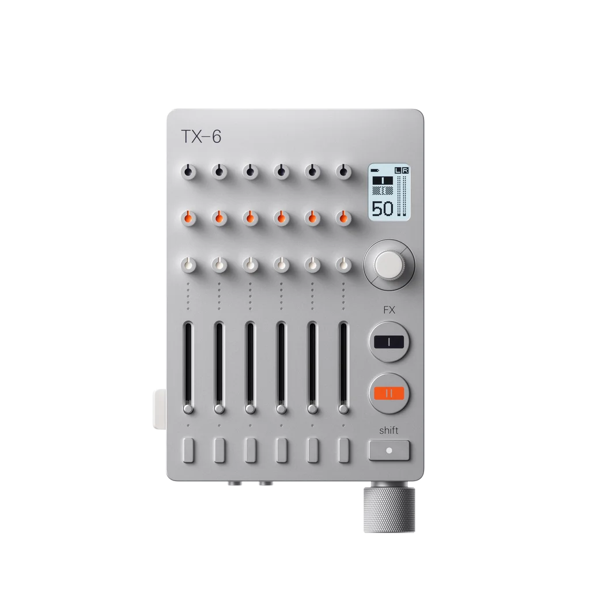
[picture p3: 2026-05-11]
docs/references/tx6_design_language/images/01_tx6_front_aluminum.webp

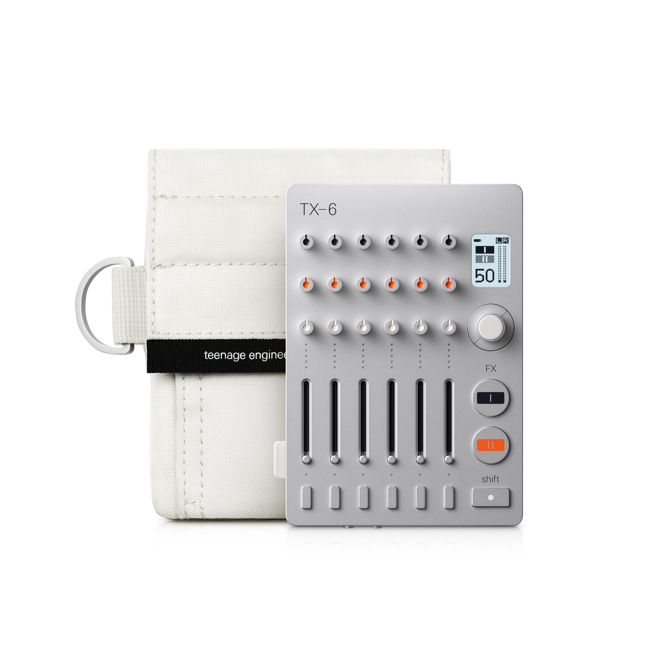
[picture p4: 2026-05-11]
docs/references/tx6_design_language/images/06_tx6_field_kit_packaging_reference.webp

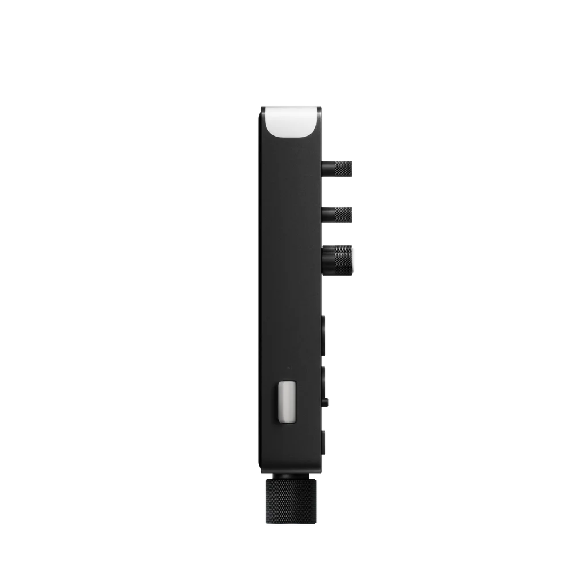
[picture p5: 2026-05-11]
docs/references/tx6_design_language/images/02_tx6_side_profile_left.webp

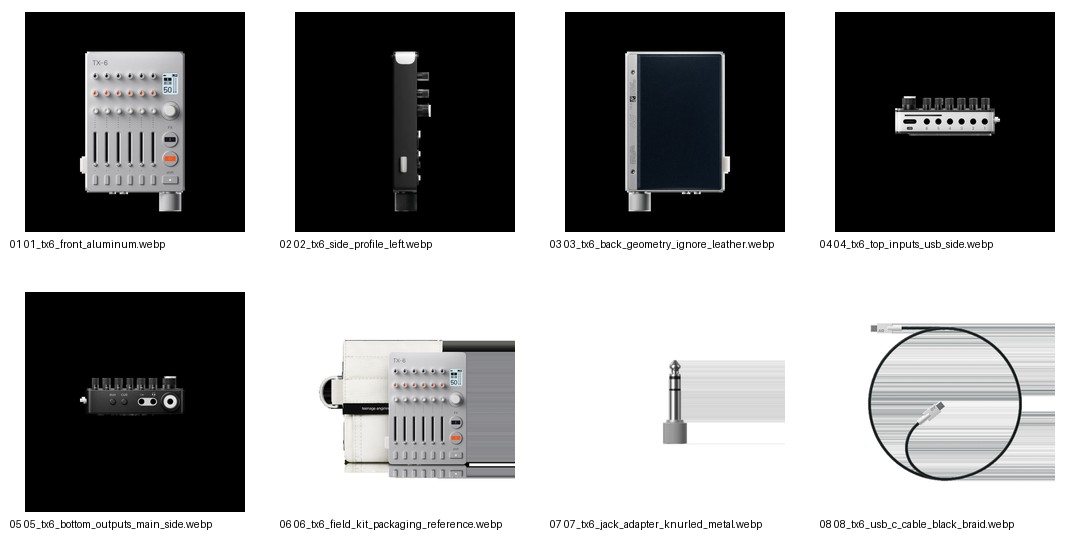
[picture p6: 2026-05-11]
docs/references/tx6_design_language/images/tx6_reference_contact_sheet.jpg

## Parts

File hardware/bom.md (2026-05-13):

# Bill of Materials

> **Status:** Skeleton — to be expanded into a full vendor-linked BOM during paper-prep. The detailed parts inventory currently lives inside `hardware/electronics/README.md` (Inventory Assessment + Missing Parts To Buy Or Confirm sections) and `hardware/machining_notes.md` (Vendor Notes + costing summary).

## Chamber body

| Part | Qty | Material | Notes |
|---|---:|---|---|
| Chamber body (machined) | 1 | 316L stainless | Electropolished + passivated wetted surfaces; CAD source `hardware/cad/source/`, machinable STEP `hardware/cad/step/base.step`, drawing `hardware/drawings/base_drawing.pdf` |
| Cover plate (machined) | 1 | 316L stainless | Same finish; STEP `hardware/cad/step/cover.step`, drawing `hardware/drawings/cover_drawing.pdf` |
| Clamp / retainer frame | 1 | 316L stainless or anodized aluminum | Non-wetted; secondary fastener for cover-glass preload |

Vendor: see `hardware/machining_notes.md` § "Vendor Notes" for Xometry vs RapidDirect cost/lead-time comparison. Expected $200–500 for the chamber + cover + clamp set in standard-tolerance tier.

## Optical and fluidics

| Part | Vendor / P/N | Qty | Notes |
|---|---|---:|---|
| Cover glass | Thorlabs **CG15KH1** #1.5H, 24 × 50 × 0.170 mm | pack | Locked optical substrate; pocket geometry in `hardware/coverglass_spec.md` |
| Sealing silicone sheet | Medical-grade **neutral-cure** silicone, 0.250 mm ± 0.025 mm, 40–50 Shore A | pack | **No RTV / no acetoxy.** Source: McMaster-Carr; laser-cut by SendCutSend or Oshcut |
| FEP/PTFE tubing, 1/16" OD | McMaster `2129T11` or equivalent | meters | Inlet/outlet to chamber |
| Pump tubing (peristaltic) | platinum-cured silicone, matched to pump head | as required | |
| Reservoir | borosilicate GL45 bottle | 1 | |
| IDEX Super Flangeless 1/4-28 fittings | IDEX / Cole-Parmer | as required | Chamber inlet / outlet |

## Pump and motor

| Part | P/N | Qty | Notes |
|---|---|---:|---|
| Peristaltic pump (24 V stepper-driven) | Kamoer KCS or equivalent | 1 | Low-pulsation head |
| 24 V DC supply, fused | sized for pump current + driver | 1 | |
| Latching motor-power switch / E-stop | NC contacts; physically removes 24 V from TMC2209 | 1 | Fail-safe; firmware-independent |
| Inline blade fuse + holder | 1–2 A starting, adjust after current measurement | 1 | |

## Electronics

| Part | Qty | Notes |
|---|---:|---|
| Teensy 4.1 (no Ethernet) | 1 | Real-time controller; onboard SDIO + microSD |
| Teensy 4.1 terminal block breakout | 1 | Wiring interface |
| TMC2209 stepper driver carrier | 1 + 1 spare | UART config, STEP/DIR drive |
| MicroSD card | 64 GB UHS-I U3 V30 A2 | Data logging |
| Sensirion **SLF3S-1300F** inline liquid flow sensor | 1 | I²C, direct flow measurement (mL/min) + media temperature on the same frame; PEEK-wetted, biocompatible, CIP-cleaned per `docs/cleaning_protocol.md`; sits in-line between pump and chamber inlet |
| AS5600 magnetic encoder breakout + magnet | 1 | Pump-shaft phase logging |
| DS18B20 waterproof temperature probes | 3–5 | Reservoir / inlet / ambient |
| 4.7 kΩ resistor (OneWire pull-up) | 1 | |
| Waveshare 1.5" RGB OLED (128 × 128 SPI) | 1 | Local status display |
| EC11 rotary encoder | 1 | Local UI |
| Tactile buttons | 3 | `prime`, `run`, `stop` |
| Optoisolators / digital isolators | 2 | BNC trigger isolation (in + out) |
| Panel-mount BNC | 1 | Microscope trigger |
| Enclosure, cable glands, strain reliefs | as required | No loose breadboard near microscope |

## Miscellaneous tooling (one-time)

- 8-channel logic analyzer (24 MHz minimum) — STEP frequency / UART / trigger timing validation
- Oscilloscope (analog) — voltage rail and signal-integrity checks
- Multimeter, ferrule crimping kit, heat shrink, 22 AWG silicone wire

## Validation rig (one-time per chamber, not in deployed device)

A separate bench instrument used once per chamber build to characterize the SLF3S-1300F response by cross-checking against an independent differential-pressure measurement on the chamber. Lives in the lab toolkit; not shipped with the chamber. See `docs/protocol.md` § "Per-chamber sensor validation" for the procedure and `hardware/electronics/README.md` § "Validation methodology" for the architecture.

| Part | Vendor / P/N | Qty | Notes |
|---|---|---:|---|
| Differential pressure sensor breakout | DFRobot **SEN0343** (All Sensors LWLP5000 ±500 Pa, I²C) | 1 | 3 mm barbed dual ports; pre-mounted on breakout with pull-ups + level shifter |
| Microcontroller (validation host) | Raspberry Pi Pico 2 (or any 3.3 V I²C-capable board) | 1 | Reads SEN0343 over I²C; dumps CSV over USB serial to bench laptop |
| Breadboard, half-size (400 tie-point) | generic | 1 | Mounts Pico + SEN0343 + jumpers |
| 0.22 µm hydrophobic membrane filters | Millipore Millex-FG (PTFE) **SLFG025LS** | 2 | Gas-side barrier between chamber standpipe and SEN0343 |
| Standpipe tubes | borosilicate or acrylic, 4–6 mm ID × 50 mm | 2 | Temporary, attached to chamber pressure-tap ports during validation runs only |
| Silicone tubing, 1/16" ID | Cole-Parmer or equivalent | 1 m | Connects standpipe → Millex-FG → SEN0343 barbs |
| Luer-to-barb adapters | 1/16" or 3/32" barb to female luer | 4 | Mates Millex-FG luer outlets to tubing |
| USB cable, Pico end | USB-A / USB-C to micro-USB or USB-C, depending on Pico revision | 1 | Pico → bench laptop for serial logging |

## To be filled in during paper-prep

- Per-row vendor links (Mouser / Digi-Key / McMaster / Sigma SKUs).
- Per-row USD pricing snapshot at publication.
- Optional µPIV validation rig parts (camera, laser, tracer beads) for the ~$500 PIV cross-validation station — see `hardware/electronics/README.md` § "µPIV validation rig".
- Calibration-day reference fluid (NIST-traceable glycerol-water) source and frequency.

See `hardware/machining_notes.md` for vendor-facing dimensional notes and `hardware/electronics/README.md` for the full electronics architecture and bench bring-up sequence.

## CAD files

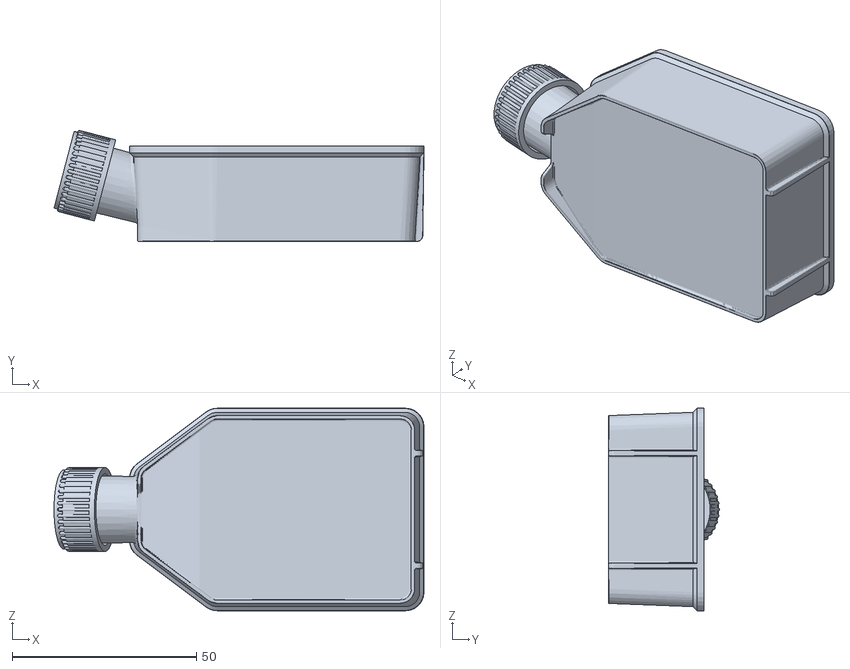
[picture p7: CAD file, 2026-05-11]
hardware/cad/components/Flask T25.stl
100.5 x 30.2 x 55.0

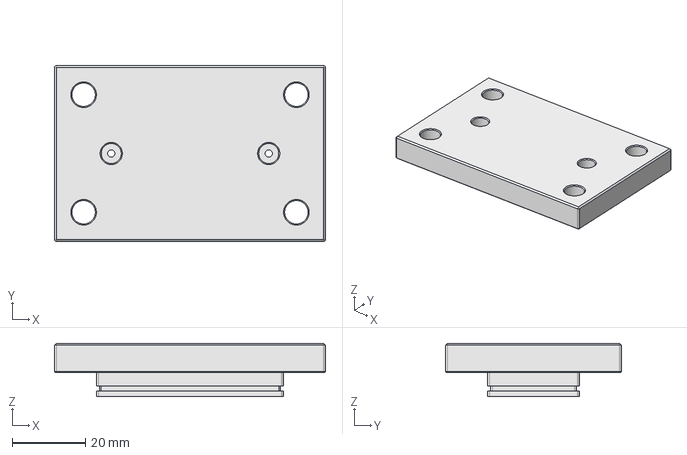
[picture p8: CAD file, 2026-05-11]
hardware/cad/step/cover.step
74.0 x 48.0 x 14.6 mm

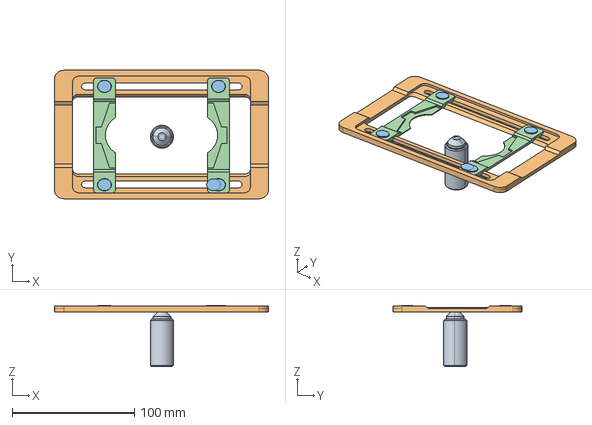
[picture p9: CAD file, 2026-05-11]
hardware/cad/components/scope_holder.stp
175.1 x 105.2 x 50.3 mm

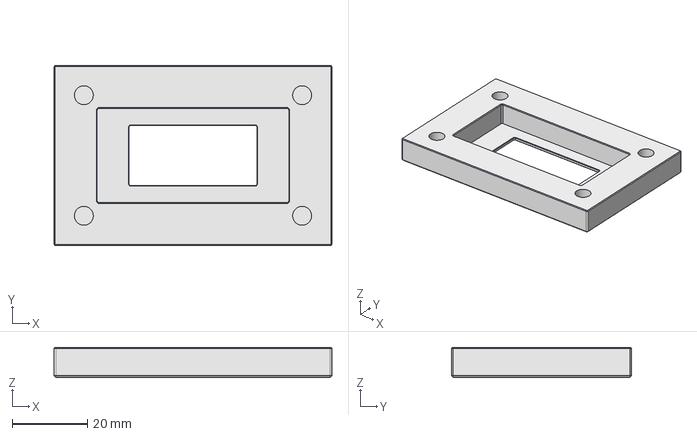
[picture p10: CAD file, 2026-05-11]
hardware/cad/step/base.step
74.0 x 48.0 x 8.00 mm

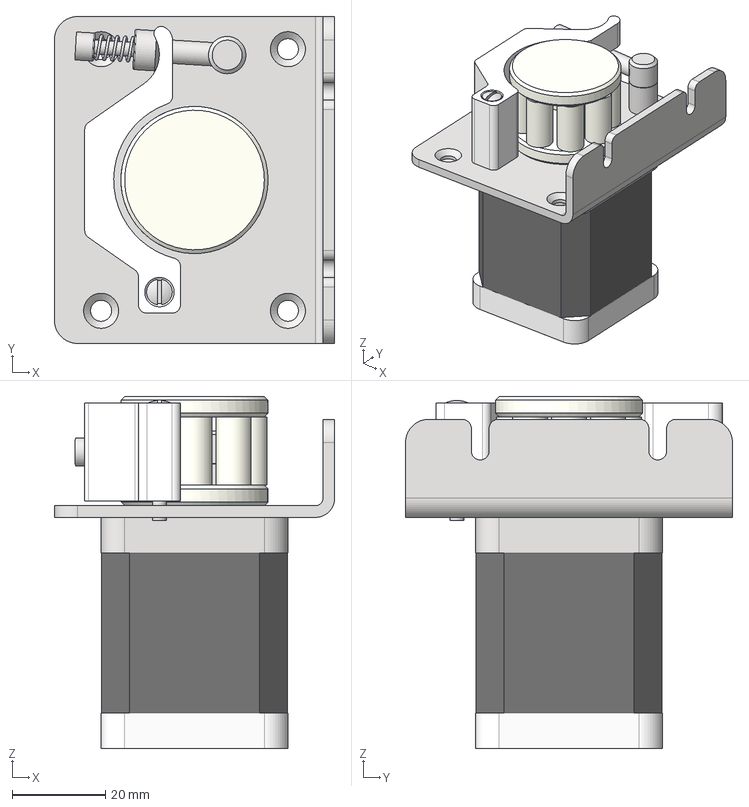
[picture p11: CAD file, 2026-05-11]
hardware/cad/components/SL8B04A_peristaltic_pump.stp
60.0 x 70.0 x 75.4 mm
KAMOER KCS plus SL8B04A
KAMOER KCS plus SL8B04A_BRACKET
ISO 2010 - M3x25
KAMOER KCS plus SL8B04A_SHTIFT

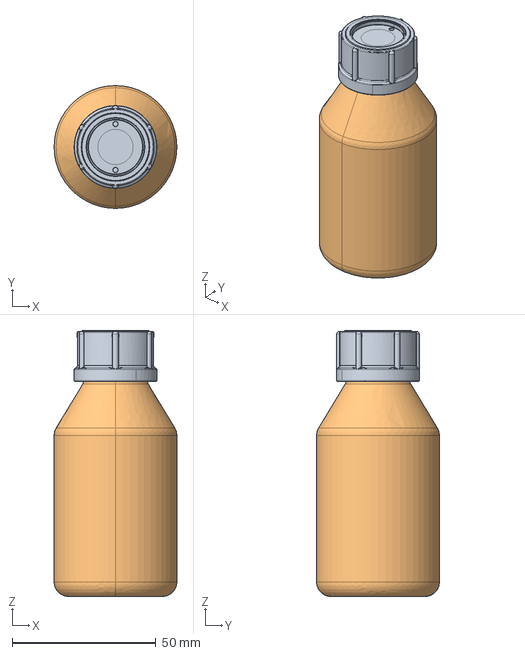
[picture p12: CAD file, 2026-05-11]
hardware/cad/components/reservoir.stp
42.7 x 42.7 x 92.4 mm

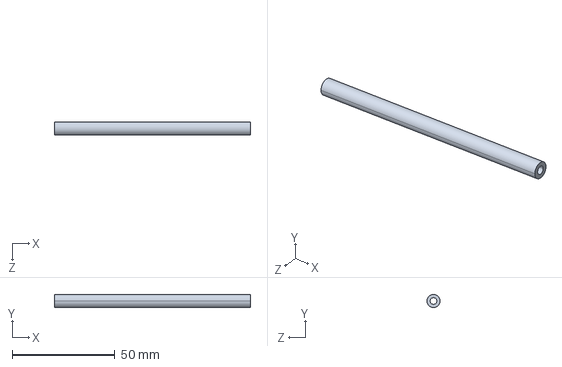
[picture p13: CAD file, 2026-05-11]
hardware/cad/components/9628N424_High-Temperature and High-Purity Soft Silicone Rubber Tubing.STEP
95.2 x 6.35 x 6.35 mm

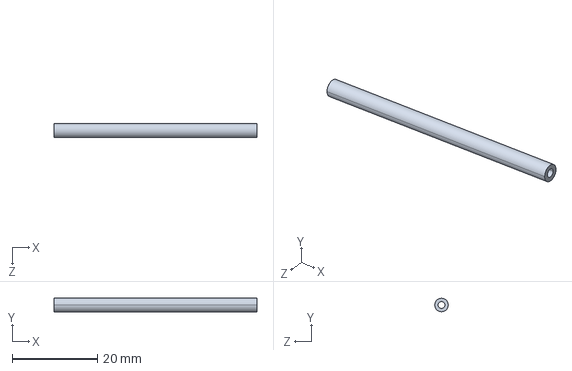
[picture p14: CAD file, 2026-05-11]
hardware/cad/components/2129T11_circuit_tubing.STEP
47.6 x 3.17 x 3.17 mm

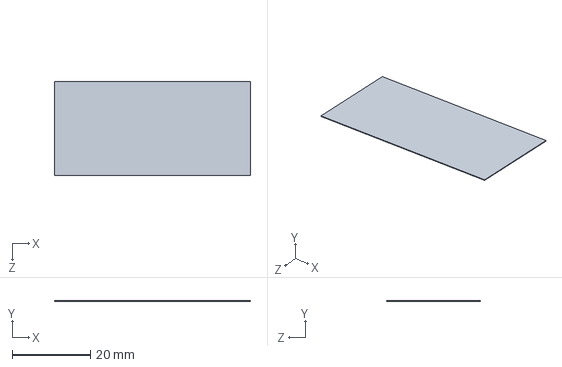
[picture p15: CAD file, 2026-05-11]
hardware/cad/components/thorlabs_coverslip_CG15KH1.step
50.0 x 0.17 x 24.0 mm

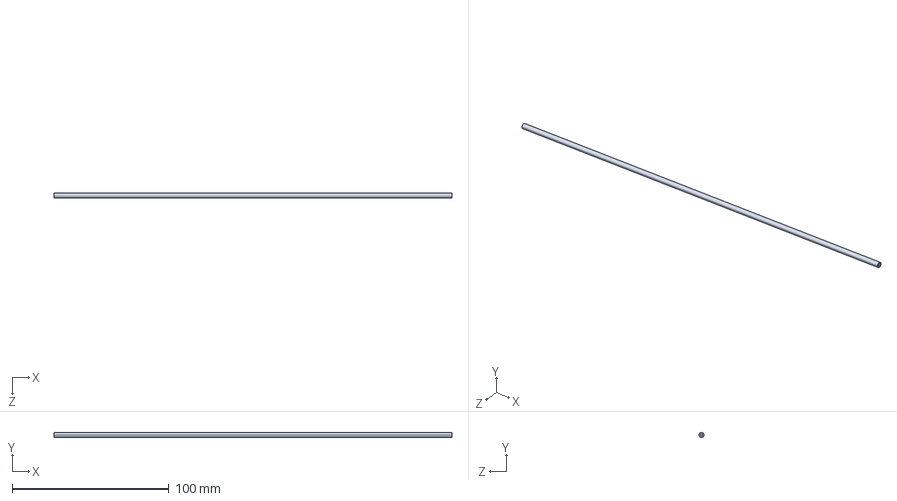
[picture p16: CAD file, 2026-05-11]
hardware/cad/components/51845K53_pump_tubing.STEP
254.0 x 3.17 x 3.17 mm

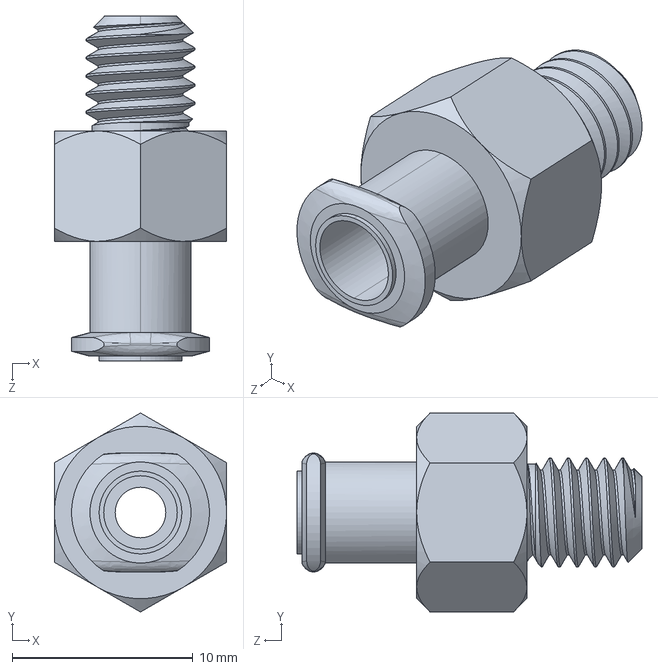
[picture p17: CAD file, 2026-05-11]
hardware/cad/components/5194K52_Quick Turn Tube Coupling for Air.STEP
9.53 x 11.0 x 19.0 mm

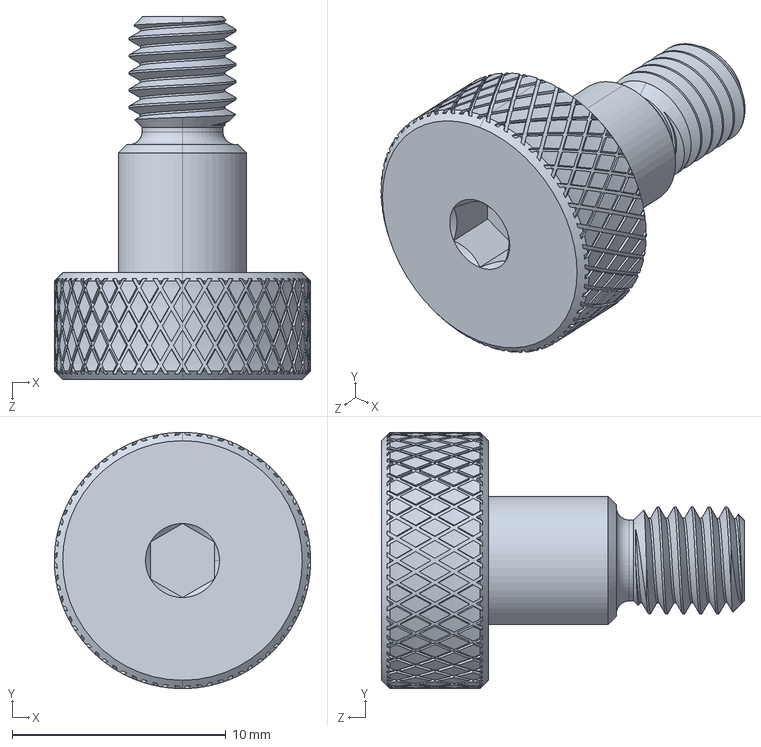
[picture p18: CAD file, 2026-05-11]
hardware/cad/components/92957A270_Thumb-Grip 18-8 Stainless Steel Precision Shoulder Screw.STEP
12.0 x 12.0 x 17.0 mm

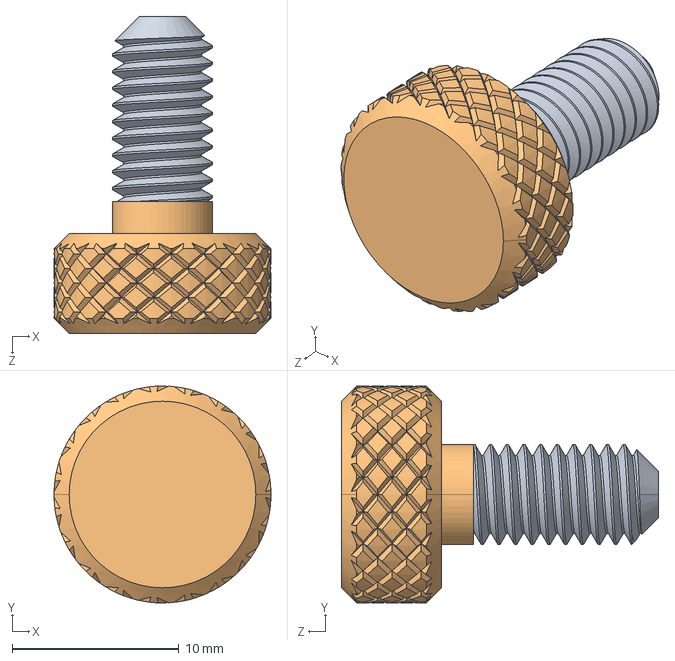
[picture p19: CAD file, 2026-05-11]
hardware/cad/components/92545A183_Knurled-Head Thumb Screw.STEP
13.0 x 13.0 x 19.0 mm

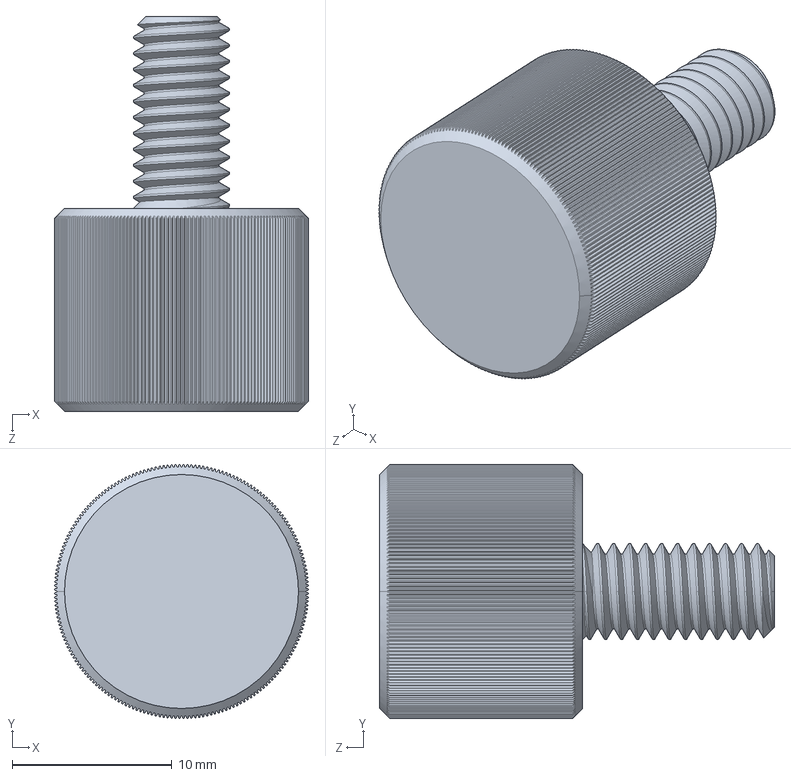
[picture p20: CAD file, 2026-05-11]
hardware/cad/components/93585A517_Stainless Steel High-Profile Knurled-Head Thumb Screw (1).STEP
15.9 x 15.9 x 24.7 mm

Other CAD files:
hardware/cad/components/90467A131_High-Pressure Bonded Sealing Washer.STEP

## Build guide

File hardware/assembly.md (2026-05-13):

# Assembly

> **Status:** Skeleton — to be authored end-to-end during paper-prep with photos at each step. The detailed wet-lab procedure (cell culture, cover-glass coating, dye loading, chamber assembly with cells, equilibration) is in `docs/protocol.md`. The bench bring-up sequence for the controller is in `hardware/electronics/README.md` § "Bench Bring-Up Checklist". This file consolidates the **mechanical assembly** (chamber + tubing + reservoir, pre-cell), gating those wet-lab and electronics flows.

## Stage 0 — receive parts

1. Inspect machined parts (chamber body, cover plate, clamp frame) against drawings in `hardware/drawings/`. Critical dimensions are flagged with `◊` on the vendor PDF.
2. Confirm cover-glass pocket clears the 24 × 50 mm Thorlabs CG15KH1 lot.
3. Confirm sealing-silicone sheet is **medical-grade neutral-cure** (per `hardware/bom.md`). Reject any RTV / acetoxy-cure stock — these byproducts are cytotoxic to MLO-Y4.
4. Inspect cover-glass support lip for burrs. Deburr if needed (jeweler's file, gentle).

## Stage 1 — pre-clean

1. Ultrasonic clean machined parts in fresh deionized water, 5 min.
2. Repeat in 70 % ethanol, 5 min.
3. Air-dry under cleanroom wipe.
4. Autoclave the chamber, cover plate, clamp, and fittings as one assembly per the chamber's autoclave cycle (typically 121 °C / 15 min / wet, or per local SOP). Do **not** autoclave the controller, the SLF3S-1300F inline flow sensor, or any other electronics — the SLF3S wetted path is CIP-cleaned in place per `docs/cleaning_protocol.md`.

## Stage 2 — gasket and channel-height stack

> The channel height is **hard-stop limited** by machined geometry, not torque-limited by screws. Do not over-tighten.

1. Lay the laser-cut silicone gasket onto the chamber lip. Gasket cutout matches the channel footprint; perimeter sits on the steel land.
2. Confirm the gasket is flat — no folds, no debris under it.
3. Drop the cover glass onto the cover-glass pocket. The glass should rest in the pocket without scraping or binding (~0.4 mm clearance per side per `coverglass_spec.md`).
4. Place the cover plate on top. Engage the clamp screws hand-tight, then torque per the spec in `hardware/machining_notes.md` § "Vendor Drawing Critical Callouts" — torque to the hard-stop only, not beyond.

## Stage 3 — fluidic loop

1. Connect the IDEX 1/4-28 luer / flat-bottom fittings to the chamber's inlet and outlet bores.
2. Route 1/16" OD FEP tubing from the reservoir → peristaltic pump → SLF3S-1300F inline flow sensor → upstream pulsation dampener → chamber inlet; from the chamber outlet → downstream pulsation dampener → reservoir return.
3. The SLF3S-1300F sits inside the controller body, downstream of the pump and upstream of the chamber. Its PEEK-wetted channel is part of the sterile loop but never autoclaved; it is CIP-cleaned in place after each experiment per `docs/cleaning_protocol.md`.
4. Verify all luer / barb engagements are seated; pinhole leaks at the SLF3S barbs introduce air slugs that damage the sensor over time.
5. If running a per-chamber validation pass (one-time, methods-only), connect the temporary standpipes + Millex-FG hydrophobic 0.22 µm separators + DFRobot SEN0343 differential pressure breakout to the chamber's pressure-tap ports. The standpipe geometry is in `hardware/electronics/README.md` § "Validation methodology". After validation, plug the pressure-tap ports and remove the standpipe stack for routine cell-experiment runs.

## Stage 4 — controller wiring

See `hardware/electronics/README.md` § "Bench Bring-Up Checklist" for the bench-validated wiring sequence. Do not connect the BNC trigger to the microscope until the isolated trigger board has been bench-validated for no-continuity between Teensy ground and BNC shield.

## Stage 5 — first wet-loop test (off-microscope)

1. Fill reservoir with phenol-red-free α-MEM (or DI water for the very first leak test).
2. Run pump at low flow (~5 mL/min) for 2–5 min. Watch for bubbles in the chamber, leaks at fittings, and SLF3S-1300F zero stability with pump off (sensor should drift to within ±0.05 mL/min of zero within 30 s of pump-off — see `docs/cleaning_protocol.md` § "Pre-experiment prime").
3. Verify dampener attenuation: with pump on at a fixed setpoint, the SLF3S sample stream at fast-mode rate should show pump-fundamental amplitude reduced ≥ 10× vs dampener-bypass mode.
4. Verify gravimetric flow calibration at 5 setpoints with a balance per `hardware/electronics/README.md` § "Calibration protocol".
5. Visually inspect every fitting, the chamber-to-cover-glass interface, and the catch tray for drips during the 30-minute water-loop test.

Only after Stage 5 passes should you connect the chamber to the microscope. The wet-run gate in the bring-up checklist is mandatory.

## Stage 6 — moving to the microscope

See `docs/protocol.md` § "Pre-experiment chamber setup" for chamber assembly with cells, equilibration, and imaging configuration.

## To be filled in during paper-prep

- Step photos (chamber pre-clean, gasket placement, cover-glass seating, clamp torque, fitting engagement, standpipe priming).
- Specific torque values per the final fastener spec.
- Time estimates per stage (e.g., autoclave 90 min, gasket placement 5 min, fluidic loop 30 min).
- Common assembly failure modes and fixes (gasket folds, glass scraping, leak at port-counterbore).

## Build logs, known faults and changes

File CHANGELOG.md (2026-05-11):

# Changelog

All notable changes to this project will be documented in this file.

The format is based on [Keep a Changelog](https://keepachangelog.com/en/1.1.0/),
and this project adheres to [Semantic Versioning](https://semver.org/spec/v2.0.0.html).

## [Unreleased]

## [0.1.0-alpha] — 2026-05-10

First packaged alpha build. The operator app is feature-complete against the
mock interface; live firmware integration resumes on the bench when the
replacement Teensy + TMC2209 land. Tracked toward the v2.0 paper-companion
release captured below — this is the first public-shape snapshot of that work.

### Added

- Electron operator app — custom frameless title bar (File / Edit / View
  dropdowns + window controls), Braun TG-60-inspired control surface, SHEAR
  major knob paired with a pump-roller wheel, OSC waveform + AMPL/FREQ minor
  knobs, RUN (ramp-in / duration / ramp-out), TRANSPORT (run/stop/spin/prime),
  CHANNEL block with a Poiseuille-flow particle visualization and live
  SHEAR/FLOW/TEMP/TIMER readouts.
- Library sidebar with study tree, multi-select runs (shift / ctrl click),
  inline rename on double-click, +group / +run shortcuts, right-click delete
  for one or many runs.
- Folder-based study persistence (JSON + CSV per run) and mock interface
  enabling hardware-free development of every UI path.
- Firmware (`firmware/`) and open-hardware artifacts (`hardware/`) staged for
  bench integration; see `[2.0.0]` below for the full v2.0 manifest.

### Known limitations

- Bench-side firmware verification deferred to the next bench session.
- No imaging-file SHA256, no run import, no auto-updater.

## [2.0.0] — TBD

Initial public release. Paper companion repo for the parametric parallel-plate flow chamber.

### Added

- Open hardware: parametric Fusion CAD (`hardware/cad/source/`), machinable STEP (`hardware/cad/step/`), vendor-facing PDF drawings (`hardware/drawings/`), third-party component STEP files (`hardware/cad/components/`), bill of materials (`hardware/bom.md`), assembly procedure (`hardware/assembly.md`), machining reference notes (`hardware/machining_notes.md`).
- Firmware for Teensy 4.1 + TMC2209: PlatformIO project under `firmware/` with deterministic STEP-pulse generation, microSD logging, isolated BNC trigger interface, watchdog, and host serial protocol.
- Electron operator app (`app/`): React 18 + TypeScript, Tailwind v4, Radix UI, motion, Zustand, uPlot. Synth-style operator surface (OSC / SHEAR / ENV / DISPLAY / SYNC / TRANSPORT / MASTER). Folder-based study persistence (JSON + CSV per run). Mock interface for hardware-free development. Mac (`.dmg`) and Windows (`.exe`/`.msi`) builds.
- Documentation: scientific theory and shear math (`docs/theory.md`), system architecture (`docs/architecture.md`), wet-lab protocol (`docs/protocol.md`), industrial design language (`docs/design_language.md`), differential-pressure shear-verification system (`hardware/electronics/README.md`), microscope and cover-glass constraints.
- Examples: a sample folder-based study (`examples/demo_study/`) demonstrating the on-disk format, with sample protocols (sine, square, triangle, DC) and run telemetry.
- Open-source ceremony files: MIT for code, CC-BY-4.0 for hardware/docs, `CITATION.cff`, `CONTRIBUTING.md`, GitHub issue templates and CI workflows.

## [1.0.0] — 2024 (retrospective)

Undergraduate honors thesis prototype (Saffari, Cornell, 2024). v1.0 was not publicly released; v2.0 (this release) is the first public release. Source materials from the thesis are preserved internally at `archive/flow_chamber_v1/thesis_source/` (out of repo scope; not shipped). The v1.0 Python/Qt controller app is preserved at `archive/flow_chamber_v1/python_v0.1_app/` as a parity reference for the v2.0 Electron port.

### Carried forward into v2.0

- Channel geometry and shear-equation framework (refined to canonical 24 mm × 50 mm × 0.25 mm).
- Folder-based study persistence schema (JSON + CSV); v2.0 wire-format is identical so old/new tooling cross-reads.
- Calcium-imaging protocol via Fura Red on the Zeiss LSM 880; updated for the canonical chamber geometry and a six-parameter waveform family.

### Superseded

- Internal v3.9 / v4.0 / v4.1 dev sprints (between v1.0 and v2.0) are retired; their work product is folded into v2.0 directly.
- v1.0 5 mm × 0.250 mm × 75 mm legacy channel; superseded by the 24 mm × 50 mm × 0.25 mm canonical channel (full cover-glass-footprint width).

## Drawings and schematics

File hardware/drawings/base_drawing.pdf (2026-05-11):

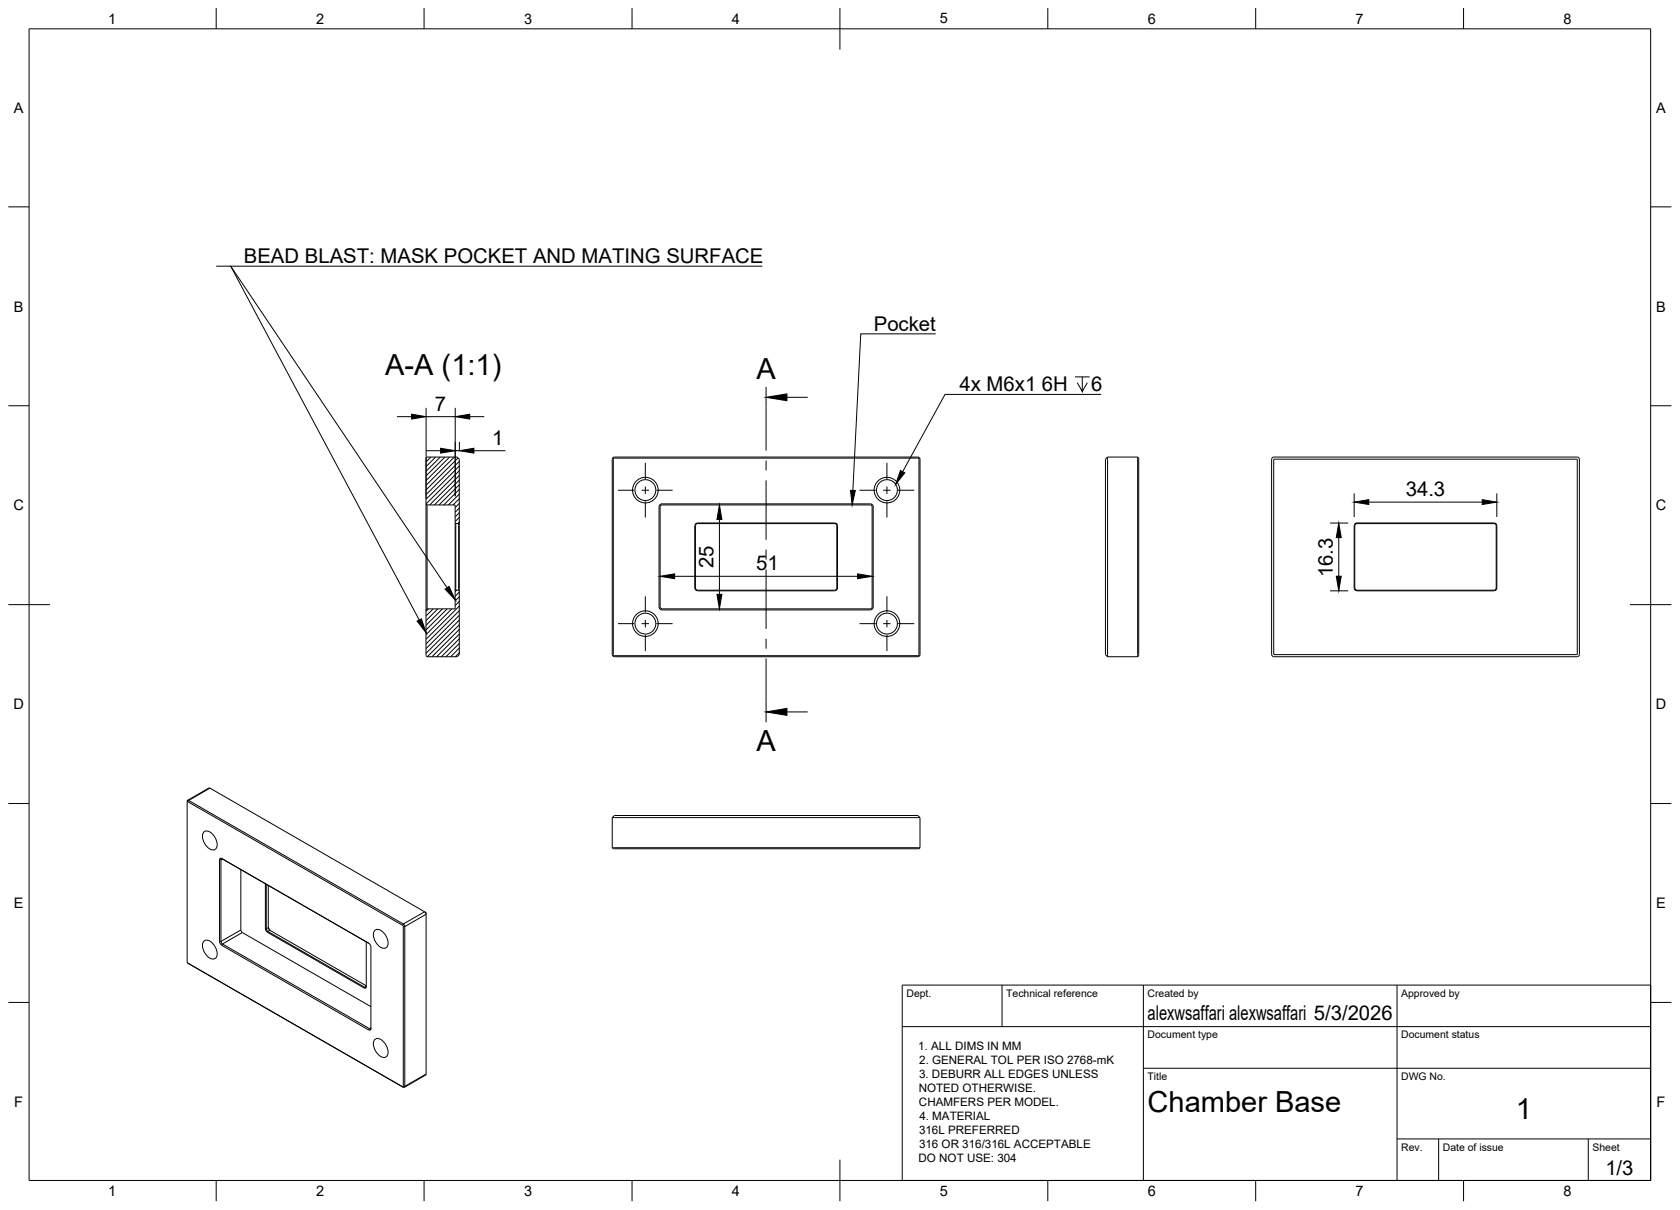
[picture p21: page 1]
alexwsaffari alexwsaffari 25

BEAD BLAST: MASK POCKET AND MATING SURFACE

Dept. | Technical reference | Created by 5/3/2026 | Approved by

1. ALL DIMS IN MM 2. GENERAL TOL PER ISO 2768-mK 3. DEBURR ALL EDGES UNLESS NOTED OTHERWISE. CHAMFERS PER MODEL. 4. MATERIAL 316L PREFERRED 316 OR 316/316L ACCEPTABLE DO NOT USE: 304 | | Document type | Document status

Title Chamber Base | DWG No. 1

Rev. | Date of issue | Sheet 1/3

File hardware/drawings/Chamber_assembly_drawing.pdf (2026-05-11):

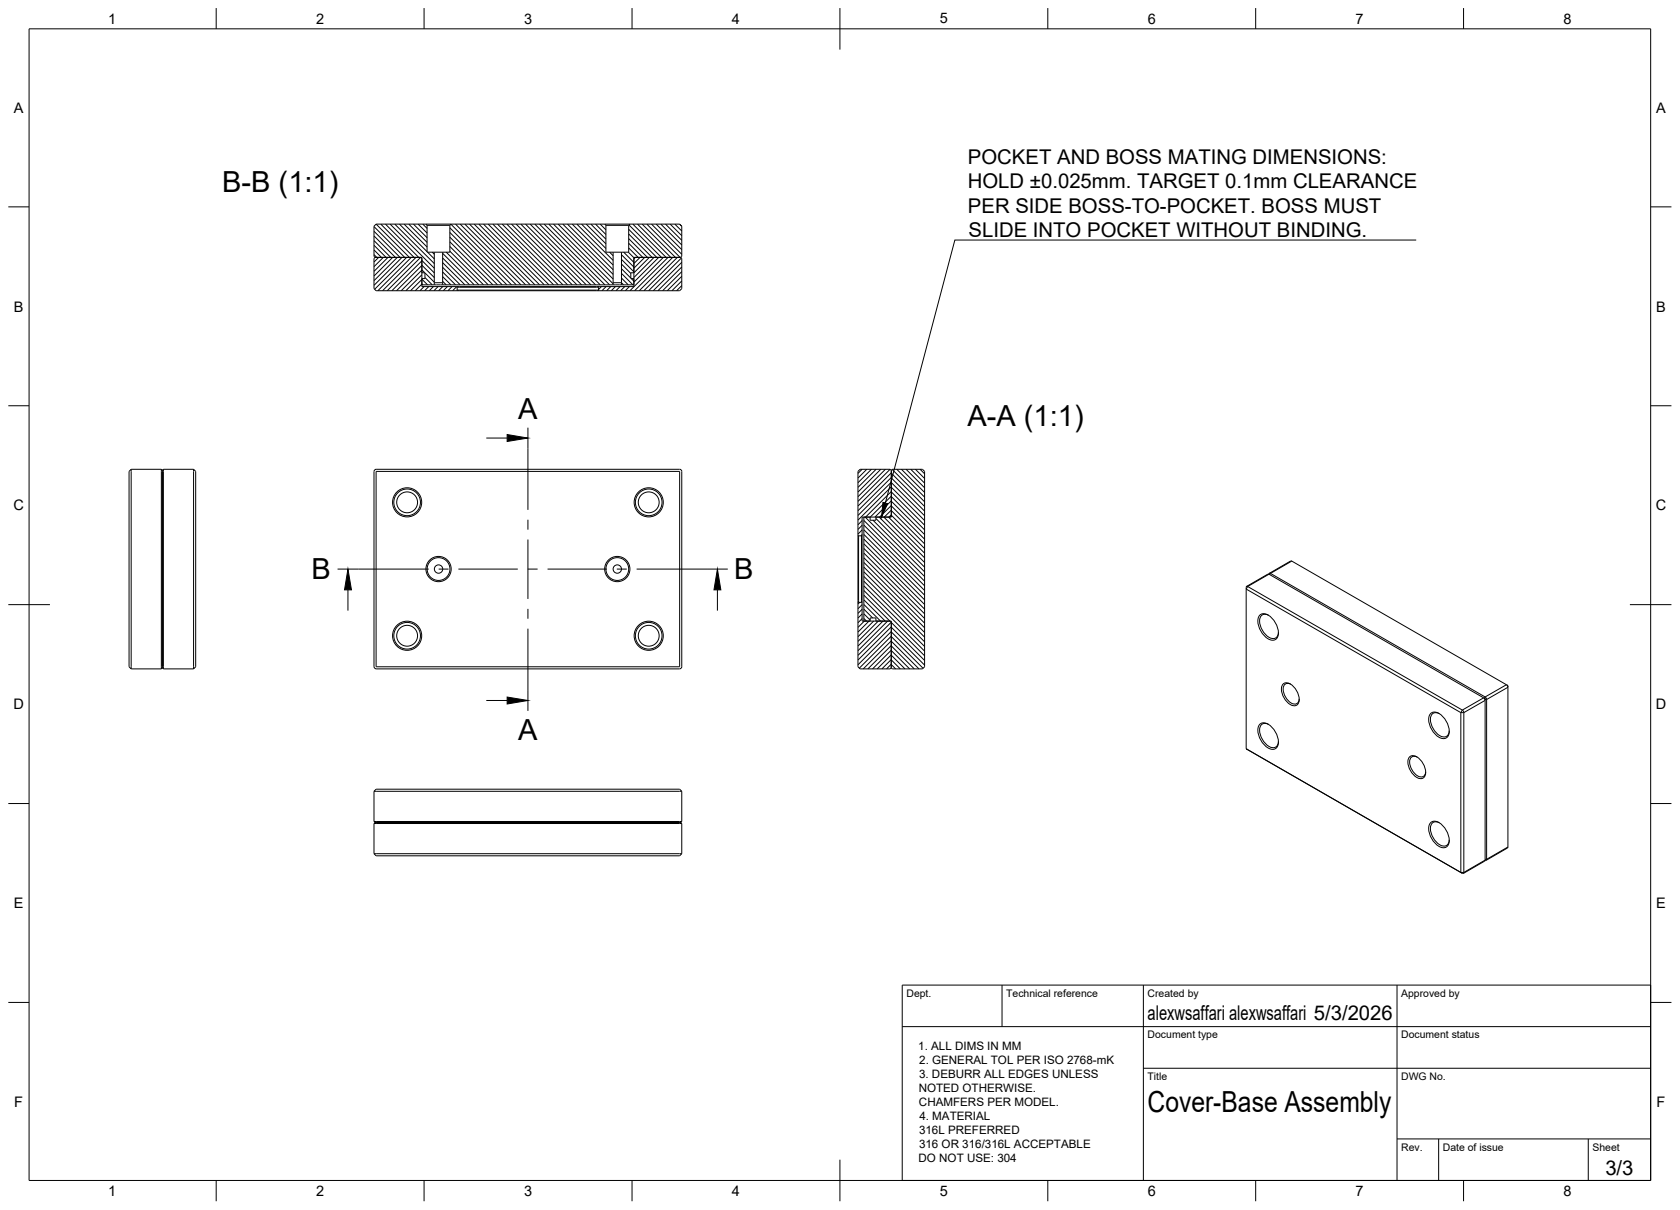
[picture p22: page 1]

POCKET AND BOSS MATING DIMENSIONS:
HOLD ±0.025mm. TARGET 0.1mm CLEARANCE
PER SIDE BOSS-TO-POCKET. BOSS MUST
SLIDE INTO POCKET WITHOUT BINDING.

Dept. | Technical reference | Created by alexwsaffari alexwsaffari 5/3/2026 | Approved by

1. ALL DIMS IN MM 2. GENERAL TOL PER ISO 2768-mK 3. DEBURR ALL EDGES UNLESS NOTED OTHERWISE. CHAMFERS PER MODEL. 4. MATERIAL 316L PREFERRED 316 OR 316/316L ACCEPTABLE DO NOT USE: 304 | | Document type | Document status

Title Cover-Base Assembly | DWG No.

Rev. | Date of issue | Sheet 3/3

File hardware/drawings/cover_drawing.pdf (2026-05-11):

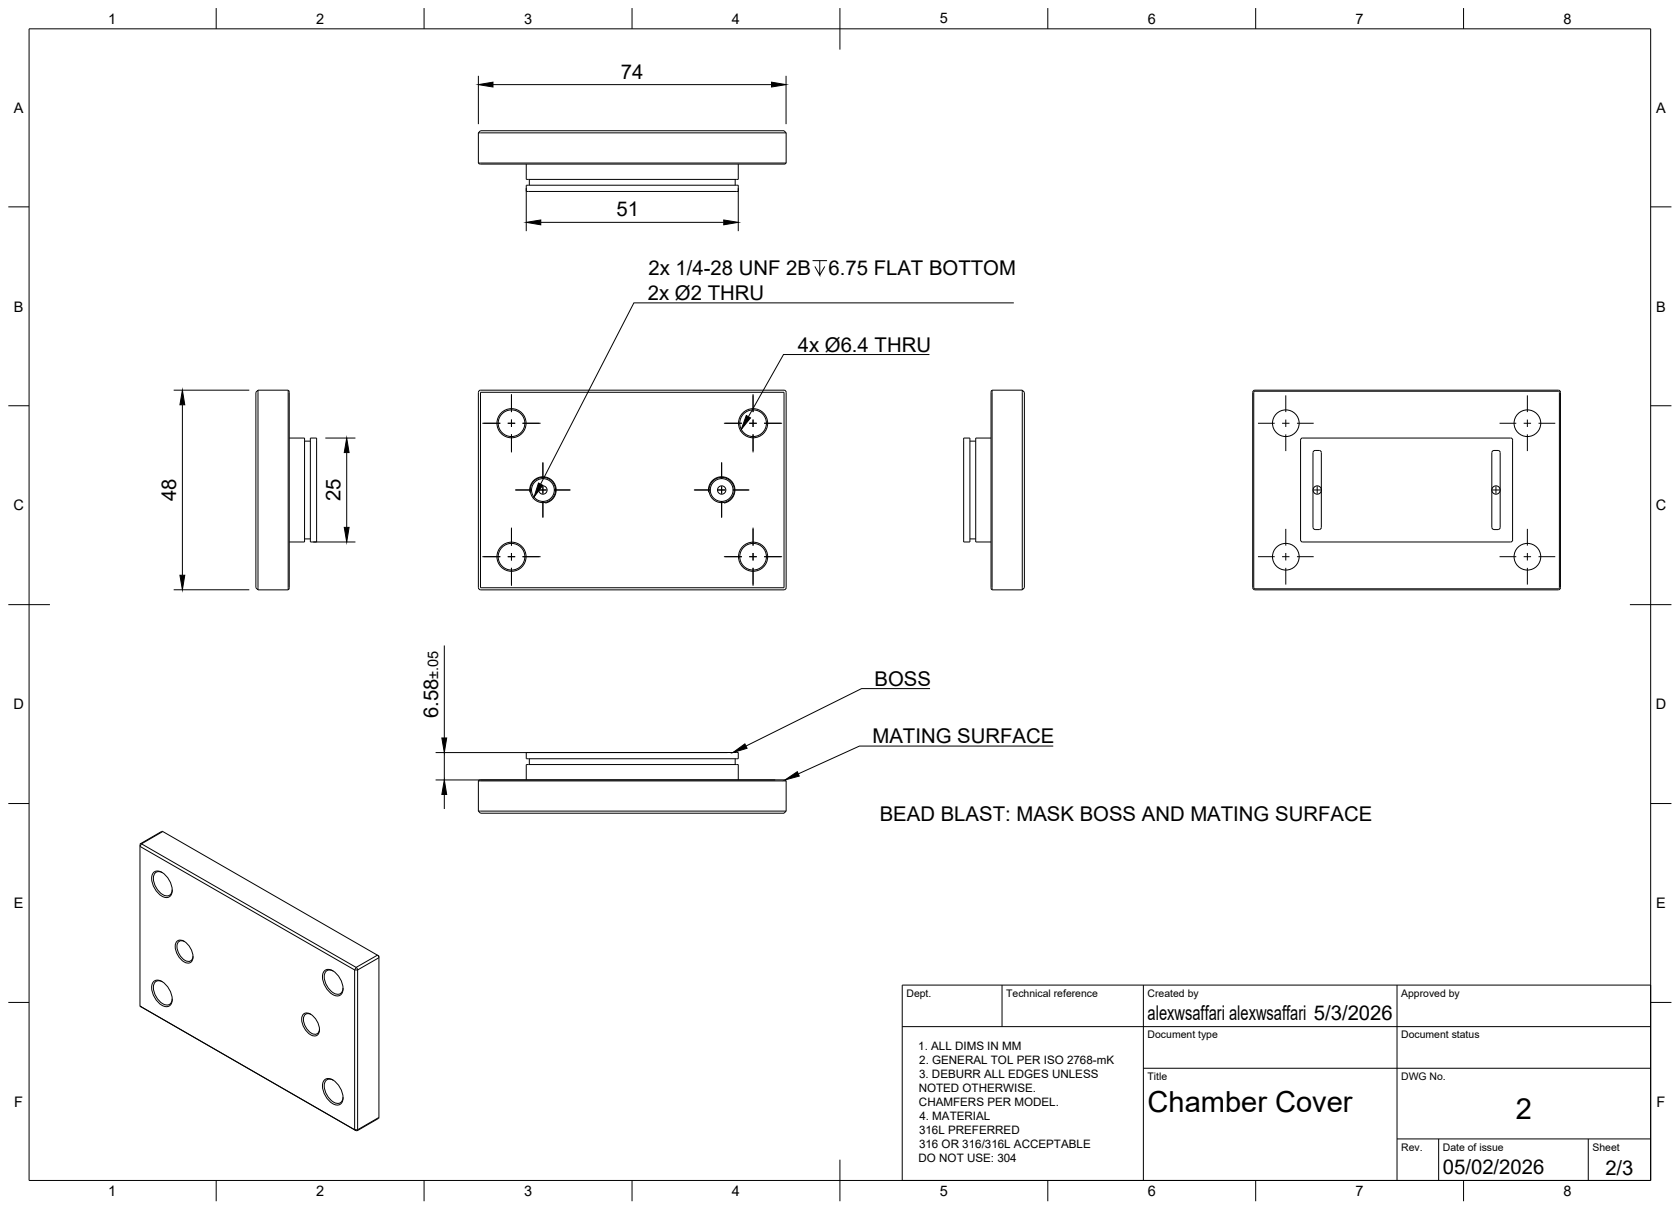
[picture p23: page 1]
4x Ø6.4 THRU 6.58±.05; MATING SURFACE

2x 1/4-28 UNF 2B 6.75 FLAT BOTTOM
2x Ø2 THRU

BEAD BLAST: MASK BOSS AND MATING SURFACE

Dept. | Technical reference | Created by alexwsaffari alexwsaffari 5/3/2026 | Approved by

1. ALL DIMS IN MM 2. GENERAL TOL PER ISO 2768-mK 3. DEBURR ALL EDGES UNLESS NOTED OTHERWISE. CHAMFERS PER MODEL. 4. MATERIAL 316L PREFERRED 316 OR 316/316L ACCEPTABLE DO NOT USE: 304 | | Document type | Document status

Title Chamber Cover | DWG No. 2

Rev. | Date of issue 05/02/2026 | Sheet 2/3

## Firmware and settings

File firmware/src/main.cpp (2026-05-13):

#include <Arduino.h>
#include <SD.h>
#include <Wire.h>
#include <ctype.h>
#include <stdio.h>
#include <stdlib.h>
#include <string.h>

#include "display.h"
#include "hardware_config.h"

namespace {

constexpr uint32_t SERIAL_BAUD = 115200;
constexpr uint32_t SERIAL_WAIT_MS = 1500;
constexpr uint32_t HEARTBEAT_INTERVAL_MS = 500;
constexpr uint32_t LOG_INTERVAL_MS = 1000;
constexpr uint32_t LOG_FLUSH_ROWS = 5;
constexpr uint32_t MIN_STEP_RATE_HZ = 1;
constexpr uint32_t MAX_STEP_RATE_HZ = 20000;
constexpr uint32_t DEFAULT_TEST_DURATION_MS = 5000;
constexpr uint32_t MAX_JOG_DURATION_MS = 30000;
constexpr char FIRMWARE_NAME[] = "flow_chamber_teensy";
constexpr char FIRMWARE_VERSION[] = "0.4.0";

enum class State {
  Booting,
  Ready,
  StepTest,
  MotorJog,
  Fault,
};

State state = State::Booting;
bool sdReady = false;
bool ledOn = false;
bool directionForward = true;
uint32_t bootMillis = 0;
uint32_t lastHeartbeatMs = 0;
uint32_t lastLogMs = 0;
uint32_t logRows = 0;
uint32_t stepAutoStopAtMs = 0;
char logPath[16] = "";
char commandBuffer[96] = "";
size_t commandLength = 0;
File logFile;
IntervalTimer stepTimer;
volatile bool stepPinHigh = false;
volatile bool driverOutputEnabled = false;
volatile uint32_t activeStepRateHz = 0;
volatile uint32_t stepCount = 0;
volatile uint32_t triggerInCount = 0;
uint32_t triggerOutCount = 0;

const char* stateName(State value) {
  switch (value) {
    case State::Booting:
      return "BOOTING";
    case State::Ready:
      return "READY";
    case State::StepTest:
      return "STEPTEST";
    case State::MotorJog:
      return "MOTORJOG";
    case State::Fault:
      return "FAULT";
  }
  return "UNKNOWN";
}

void setPumpDisabled() {
  stepTimer.end();
  stepPinHigh = false;
  activeStepRateHz = 0;
  driverOutputEnabled = false;
  digitalWrite(hw::PIN_TMC_STEP, LOW);
  digitalWrite(hw::PIN_TMC_DIR, LOW);
  digitalWrite(hw::PIN_TMC_ENABLE, hw::TMC_DISABLE_LEVEL);
  stepAutoStopAtMs = 0;
}

void stepPulseIsr() {
  stepPinHigh = !stepPinHigh;
  digitalWriteFast(hw::PIN_TMC_STEP, stepPinHigh ? HIGH : LOW);
  if (stepPinHigh) {
    stepCount++;
  }
}

// ISR for incoming microscope frame triggers on PIN_TRIGGER_IN.
// Increments a counter only — keeps ISR minimal (no SD, no malloc, no blocking).
void triggerInIsr() {
  triggerInCount++;
}

bool startStepOutput(uint32_t stepRateHz, uint32_t durationMs, bool enableDriver) {
  if (stepRateHz < MIN_STEP_RATE_HZ || stepRateHz > MAX_STEP_RATE_HZ) {
    return false;
  }

  stepTimer.end();
  stepPinHigh = false;
  activeStepRateHz = stepRateHz;
  stepCount = 0;
  driverOutputEnabled = enableDriver;

  digitalWrite(hw::PIN_TMC_STEP, LOW);
  digitalWrite(hw::PIN_TMC_DIR, directionForward ? LOW : HIGH);
  digitalWrite(hw::PIN_TMC_ENABLE, enableDriver ? hw::TMC_ENABLE_ACTIVE_LEVEL : hw::TMC_DISABLE_LEVEL);

  const uint32_t halfPeriodUs = 500000UL / stepRateHz;
  if (!stepTimer.begin(stepPulseIsr, halfPeriodUs)) {
    setPumpDisabled();
    return false;
  }

  // durationMs == 0 is the continuous-run sentinel: leave stepAutoStopAtMs at
  // 0 so updateAutoStop() never triggers. Halt with explicit STOP or RATE 0.
  stepAutoStopAtMs = (durationMs > 0) ? (millis() + durationMs) : 0;
  return true;
}

void printHelp() {
  Serial.println("OK commands:");
  Serial.println("  PING                    -> liveness check");
  Serial.println("  STATUS?                 -> board, SD, log, step, trigger status");
  Serial.println("  LOGTEST                 -> append one manual SD log row");
  Serial.println("  SDTEST                  -> reopen/create SD smoke log");
  Serial.println("  DIR 0|1                 -> set future motor direction");
  Serial.println("  STEPTEST <hz> [ms]      -> pulse STEP with driver disabled");
  Serial.println("  JOG <hz> [ms|0]         -> driver enabled; ms=0 = continuous (STOP to halt)");
  Serial.println("  RATE <hz>               -> live update step rate during active run");
  Serial.println("  TRIGGER [us]            -> fire BNC trigger OUT pulse (default 100us)");
  Serial.println("  TRIGGER_RESET           -> zero the trigger-in counter");
  Serial.println("  STOP                    -> force pump outputs disabled");
  Serial.println("  HELP                    -> show this list");
}

bool appendLogRow(const char* eventName) {
  if (!sdReady || !logFile) {
    return false;
  }

  const uint32_t now = millis();
  logFile.print(now);
  logFile.print(',');
  logFile.print(now - bootMillis);
  logFile.print(',');
  logFile.print(stateName(state));
  logFile.print(',');
  logFile.print(eventName);
  logFile.print(',');
  logFile.print(ledOn ? 1 : 0);
  logFile.print(',');
  logFile.print(activeStepRateHz);
  logFile.print(',');
  logFile.print(stepCount);
  logFile.print(',');
  logFile.println(driverOutputEnabled ? 1 : 0);

  logRows++;
  if ((logRows % LOG_FLUSH_ROWS) == 0 || strcmp(eventName, "manual") == 0) {
    logFile.flush();
  }

  return true;
}

void stopStepOutput(const char* eventName) {
  setPumpDisabled();
  state = State::Ready;
  appendLogRow(eventName);
}

void closeLog() {
  if (logFile) {
    logFile.flush();
    logFile.close();
  }
}

bool openSmokeLog() {
  closeLog();
  sdReady = false;
  logRows = 0;
  logPath[0] = '\0';

  if (!SD.begin(hw::PIN_SD_CARD)) {
    return false;
  }

  bool foundLogSlot = false;
  for (uint8_t index = 0; index < 100; index++) {
    snprintf(logPath, sizeof(logPath), "SMOKE%02u.CSV", index);
    if (!SD.exists(logPath)) {
      foundLogSlot = true;
      break;
    }
  }

  if (!foundLogSlot) {
    logPath[0] = '\0';
    return false;
  }

  logFile = SD.open(logPath, FILE_WRITE);
  if (!logFile) {
    return false;
  }

  logFile.println("timestamp_ms,uptime_ms,state,event,led,step_rate_hz,step_count,driver_enabled");
  logFile.flush();
  sdReady = true;
  appendLogRow("boot");
  return true;
}

void printStatus() {
  Serial.print("OK name=");
  Serial.print(FIRMWARE_NAME);
  Serial.print(" version=");
  Serial.print(FIRMWARE_VERSION);
  Serial.print(" state=");
  Serial.print(stateName(state));
  Serial.print(" uptime_ms=");
  Serial.print(millis() - bootMillis);
  Serial.print(" sd=");
  Serial.print(sdReady ? "ready" : "missing");
  Serial.print(" log=");
  Serial.print(sdReady ? logPath : "none");
  Serial.print(" rows=");
  Serial.print(logRows);
  Serial.print(" step_rate_hz=");
  Serial.print(activeStepRateHz);
  Serial.print(" step_count=");
  Serial.print(stepCount);
  Serial.print(" dir=");
  Serial.print(directionForward ? 1 : 0);
  Serial.print(" driver_enabled=");
  Serial.print(driverOutputEnabled ? 1 : 0);
  Serial.print(" pump_enable_pin=");
  Serial.print(hw::PIN_TMC_ENABLE);
  Serial.print(" trigger_in_count=");
  Serial.print(triggerInCount);
  Serial.print(" trigger_out_count=");
  Serial.print(triggerOutCount);
  Serial.print(" pump=");
  Serial.println(driverOutputEnabled ? "enabled" : "disabled");
}

uint32_t parseUnsignedArg(uint32_t fallback) {
  char* token = strtok(nullptr, " \t");
  if (token == nullptr) {
    return fallback;
  }

  char* end = nullptr;
  const unsigned long parsed = strtoul(token, &end, 10);
  if (end == token || *end != '\0') {
    return fallback;
  }

  return static_cast<uint32_t>(parsed);
}

uint32_t constrainedDuration(uint32_t durationMs) {
  if (durationMs == 0) {
    return DEFAULT_TEST_DURATION_MS;
  }
  if (durationMs > MAX_JOG_DURATION_MS) {
    return MAX_JOG_DURATION_MS;
  }
  return durationMs;
}

void handleCommand(char* command) {
  while (*command == ' ' || *command == '\t') {
    command++;
  }

  for (char* cursor = command; *cursor != '\0'; cursor++) {
    *cursor = static_cast<char>(toupper(*cursor));
  }

  char* verb = strtok(command, " \t");
  if (verb == nullptr) {
    return;
  }

  if (strcmp(verb, "PING") == 0) {
    Serial.print("PONG ");
    Serial.print(FIRMWARE_NAME);
    Serial.print(" ");
    Serial.println(FIRMWARE_VERSION);
  } else if (strcmp(verb, "STATUS") == 0 || strcmp(verb, "STATUS?") == 0) {
    printStatus();
  } else if (strcmp(verb, "HELP") == 0 || strcmp(verb, "?") == 0) {
    printHelp();
  } else if (strcmp(verb, "STOP") == 0) {
    stopStepOutput("stop");
    Serial.println("OK pump outputs disabled");
  } else if (strcmp(verb, "LOGTEST") == 0) {
    if (appendLogRow("manual")) {
      Serial.print("OK wrote ");
      Serial.println(logPath);
    } else {
      Serial.println("ERR SD log is not open");
    }
  } else if (strcmp(verb, "SDTEST") == 0) {
    if (openSmokeLog()) {
      Serial.print("OK SD log opened ");
      Serial.println(logPath);
    } else {
      Serial.println("ERR SD init/open failed");
    }
  } else if (strcmp(verb, "DIR") == 0) {
    if (activeStepRateHz != 0) {
      Serial.println("ERR stop before changing direction");
      return;
    }

    const uint32_t direction = parseUnsignedArg(directionForward ? 1 : 0);
    if (direction > 1) {
      Serial.println("ERR direction must be 0 or 1");
      return;
    }

    directionForward = direction == 1;
    digitalWrite(hw::PIN_TMC_DIR, directionForward ? LOW : HIGH);
    appendLogRow("dir");
    Serial.print("OK dir=");
    Serial.println(directionForward ? 1 : 0);
  } else if (strcmp(verb, "STEPTEST") == 0) {
    const uint32_t stepRateHz = parseUnsignedArg(0);
    const uint32_t durationMs = constrainedDuration(parseUnsignedArg(DEFAULT_TEST_DURATION_MS));
    if (!startStepOutput(stepRateHz, durationMs, false)) {
      Serial.println("ERR STEPTEST range is 1..20000 Hz");
      return;
    }

    state = State::StepTest;
    appendLogRow("steptest");
    Serial.print("OK steptest_hz=");
    Serial.print(stepRateHz);
    Serial.print(" duration_ms=");
    Serial.println(durationMs);
  } else if (strcmp(verb, "JOG") == 0) {
    const uint32_t stepRateHz = parseUnsignedArg(0);
    // Default duration is 0 (continuous). Run the duration through the upper
    // bound only when explicitly nonzero — preserves the 30 s safety cap on
    // bounded jogs while letting `JOG <hz> 0` (or `JOG <hz>`) run indefinitely.
    const uint32_t rawDurationMs = parseUnsignedArg(0);
    const uint32_t durationMs = (rawDurationMs == 0) ? 0 : constrainedDuration(rawDurationMs);
    if (!startStepOutput(stepRateHz, durationMs, true)) {
      Serial.println("ERR JOG range is 1..20000 Hz");
      return;
    }

    state = State::MotorJog;
    appendLogRow("jog");
    Serial.print("OK jog_hz=");
    Serial.print(stepRateHz);
    Serial.print(" duration_ms=");
    Serial.print(durationMs);
    Serial.println(" driver_enabled=1");
  } else if (strcmp(verb, "RATE") == 0) {
    // Live step-rate update during an active run. Updates the IntervalTimer
    // period in place — no STEP-edge restart click — so the operator can
    // dial speed continuously while the pump is spinning.
    const uint32_t stepRateHz = parseUnsignedArg(0);
    if (stepRateHz < MIN_STEP_RATE_HZ || stepRateHz > MAX_STEP_RATE_HZ) {
      Serial.println("ERR RATE range is 1..20000 Hz");
      return;
    }
    if (activeStepRateHz == 0) {
      Serial.println("ERR no active run; start with JOG first");
      return;
    }
    const uint32_t halfPeriodUs = 500000UL / stepRateHz;
    // IntervalTimer::update() returns void on Teensy 4.x core; it adjusts the
    // already-running timer's period in place and cannot fail at this level.
    // Failure modes (timer not running, etc.) are guarded above by the
    // activeStepRateHz == 0 check.
    stepTimer.update(halfPeriodUs);
    activeStepRateHz = stepRateHz;
    appendLogRow("rate");
    Serial.print("OK rate_hz=");
    Serial.println(stepRateHz);
  } else if (strcmp(verb, "TRIGGER") == 0) {
    // Fire a pulse on PIN_TRIGGER_OUT for the requested duration in microseconds.
    // Used to drive the microscope BNC trigger via the isolated trigger board.
    // Default pulse 100us — well above the typical microscope minimum
    // detectable pulse width and short enough not to disturb the main loop.
    constexpr uint32_t MAX_TRIGGER_US = 10000;  // 10ms cap
    constexpr uint32_t DEFAULT_TRIGGER_US = 100;
    uint32_t pulseUs = parseUnsignedArg(DEFAULT_TRIGGER_US);
    if (pulseUs == 0 || pulseUs > MAX_TRIGGER_US) {
      Serial.println("ERR TRIGGER pulse must be 1..10000 us");
      return;
    }
    digitalWriteFast(hw::PIN_TRIGGER_OUT, HIGH);
    delayMicroseconds(pulseUs);
    digitalWriteFast(hw::PIN_TRIGGER_OUT, LOW);
    triggerOutCount++;
    appendLogRow("trigger_out");
    Serial.print("OK trigger_out_us=");
    Serial.print(pulseUs);
    Serial.print(" trigger_out_count=");
    Serial.println(triggerOutCount);
  } else if (strcmp(verb, "TRIGGER_RESET") == 0) {
    noInterrupts();
    triggerInCount = 0;
    interrupts();
    triggerOutCount = 0;
    appendLogRow("trigger_reset");
    Serial.println("OK trigger counters reset");
  } else {
    Serial.print("ERR unknown command: ");
    Serial.println(verb);
  }
}

void pollSerial() {
  while (Serial.available() > 0) {
    const char input = static_cast<char>(Serial.read());

    if (input == '\r') {
      continue;
    }

    if (input == '\n') {
      commandBuffer[commandLength] = '\0';
      handleCommand(commandBuffer);
      commandLength = 0;
      return;
    }

    if (commandLength < sizeof(commandBuffer) - 1) {
      commandBuffer[commandLength++] = input;
    } else {
      commandLength = 0;
      Serial.println("ERR command too long");
    }
  }
}

void updateHeartbeat() {
  const uint32_t now = millis();
  if (now - lastHeartbeatMs < HEARTBEAT_INTERVAL_MS) {
    return;
  }

  lastHeartbeatMs = now;
  ledOn = !ledOn;
  digitalWrite(hw::PIN_LED, ledOn ? HIGH : LOW);
}

void updatePeriodicLog() {
  const uint32_t now = millis();
  if (now - lastLogMs < LOG_INTERVAL_MS) {
    return;
  }

  lastLogMs = now;
  appendLogRow("heartbeat");
}

void updateAutoStop() {
  if (stepAutoStopAtMs == 0) {
    return;
  }

  if (static_cast<int32_t>(millis() - stepAutoStopAtMs) >= 0) {
    stopStepOutput("auto_stop");
    Serial.println("OK auto stop");
  }
}

}  // namespace

void setup() {
  bootMillis = millis();

  pinMode(hw::PIN_LED, OUTPUT);
  pinMode(hw::PIN_TMC_STEP, OUTPUT);
  pinMode(hw::PIN_TMC_DIR, OUTPUT);
  pinMode(hw::PIN_TMC_ENABLE, OUTPUT);
  pinMode(hw::PIN_TRIGGER_OUT, OUTPUT);
  pinMode(hw::PIN_TRIGGER_IN, INPUT_PULLUP);

  digitalWrite(hw::PIN_TRIGGER_OUT, LOW);
  setPumpDisabled();

  // Microscope frame trigger: count rising edges on the isolated input.
  attachInterrupt(digitalPinToInterrupt(hw::PIN_TRIGGER_IN), triggerInIsr, RISING);

  Serial.begin(SERIAL_BAUD);
  while (!Serial && millis() - bootMillis < SERIAL_WAIT_MS) {
    updateHeartbeat();
  }

  Serial.println();
  Serial.print("BOOT ");
  Serial.print(FIRMWARE_NAME);
  Serial.print(" ");
  Serial.println(FIRMWARE_VERSION);
  Serial.println("BOOT pump outputs disabled");

  if (openSmokeLog()) {
    Serial.print("BOOT SD log opened ");
    Serial.println(logPath);
  } else {
    Serial.println("BOOT SD log unavailable; insert/format microSD and send SDTEST");
  }

  // Bench OLED on default I²C bus (Teensy pins 18 SDA / 19 SCL). Non-fatal
  // if it's unplugged or missing — we only log a one-line warning and keep
  // booting. The motor + serial paths must not depend on the display.
  Wire.begin();
  if (!display_setup()) {
    Serial.println("BOOT display not detected on I2C (skipping)");
  } else {
    Serial.println("BOOT display ready (SSD1327 @ I2C0)");
  }

  state = State::Ready;
  appendLogRow("ready");
  printHelp();
  display_invalidate();
}

void loop() {
  pollSerial();
  updateHeartbeat();
  updatePeriodicLog();
  updateAutoStop();

  // Snapshot the anonymous-namespace globals into a struct the display
  // module can consume without poking into our internal linkage. The display
  // throttles itself to 10 Hz, so this snapshot is cheap regardless.
  DisplayData snap = {
    .state_name    = stateName(state),
    .step_rate_hz  = activeStepRateHz,
    .step_count    = stepCount,
    .trigger_count = triggerInCount,
    .dir_forward   = directionForward,
    .boot_millis   = bootMillis,
  };
  display_tick(millis(), snap);
}

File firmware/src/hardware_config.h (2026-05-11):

#pragma once

#include <Arduino.h>

namespace hw {

constexpr uint8_t PIN_LED = LED_BUILTIN;

// Keep the first pump driver physically safe during bring-up.
// Most TMC2209 carrier boards use active-low ENABLE, so HIGH means disabled.
constexpr uint8_t PIN_TMC_STEP = 2;
constexpr uint8_t PIN_TMC_DIR = 3;
constexpr uint8_t PIN_TMC_ENABLE = 4;
constexpr bool TMC_ENABLE_ACTIVE_LEVEL = LOW;
constexpr bool TMC_DISABLE_LEVEL = !TMC_ENABLE_ACTIVE_LEVEL;

constexpr uint8_t PIN_TRIGGER_OUT = 5;
constexpr uint8_t PIN_TRIGGER_IN = 6;

constexpr uint8_t PIN_OLED_RST = 8;
constexpr uint8_t PIN_OLED_DC = 9;
constexpr uint8_t PIN_OLED_CS = 10;

constexpr uint8_t PIN_ONEWIRE = 20;

constexpr uint8_t PIN_ENCODER_A = 24;
constexpr uint8_t PIN_ENCODER_B = 25;
constexpr uint8_t PIN_ENCODER_SW = 26;

constexpr int PIN_SD_CARD = BUILTIN_SDCARD;

}  // namespace hw

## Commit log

2026-05-11 v0.1.0-alpha — initial commit
    First packaged alpha build of the parametric flow chamber paper-companion
    repo. App is feature-complete against the mock interface; firmware and
    open-hardware artifacts are staged for bench integration when replacement
    Teensy + TMC2209 arrive.
    See CHANGELOG.md [0.1.0-alpha] for the artifact manifest.
    [2129T11_circuit_tubing.STEP, 51845K53_pump_tubing.STEP, 5194K52_Quick Turn Tube Coupling for Air.STEP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]
2026-05-11 ci: fix lint, drop pip cache requiring missing lockfile
    Three CI fixes from the first run:
    - SettingsDrawer.tsx: empty `interface PortInfoLocal extends PortInfo` was a
    pre-existing lint error that surfaced once CI ran the full ESLint pass.
    Switched to `type PortInfoLocal = PortInfo` per
    @typescript-eslint/no-empty-object-type.
    - forge.config.ts: stale `// eslint-disable-next-line no-console` directive
    was flagged unused after the lint config picked up the relevant globals;
    dropped it.
    - ci.yml firmware job: removed `cache: "pip"` because firmware/ has no
    Python requirements lockfile, so the action's cache-key resolution
    failed at Setup Python in ~6s. Re-enable with cache-depen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
2026-05-11 ci: add release workflow — tag push builds DMG + EXE and attaches to GitHub Release
    Triggers on `v*` tag push (or manual dispatch). Builds the app on
    macos-latest + windows-latest via electron-forge make, uploads the
    resulting .dmg / .zip / .exe / .nupkg, and creates / updates the
    corresponding GitHub Release with all files attached. Marked as a
    pre-release when the tag contains alpha / beta / rc.
    Lets non-developers download a Mac DMG from
    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
2026-05-13 docs: add cleaning_protocol.md
    Bench procedure for the controller-side flow loop (pump + SLF3S-1300F
    inline flow sensor + tubing + fittings). Documents four cycle types
    that all run through the existing pump:
    - Standard end-of-run CIP (~45 min, lead reagent 70% IPA): 7-phase
    water/Tergazyme/IPA/sterile-rinse cycle with forward+reverse pump
    segments for fitting dead-zone clearance. Canonical between-runs
    procedure for methods-section citation.
    - Weekly deep clean (~90 min): replaces the IPA phase with Minncare
    1:100 peracetic acid at 30 min contact + triple sterile rinse.
    - Pre-shipment / long storage: IPA fill before transit.
    - Pre-experiment prime: media-prime the loop + SLF3S zero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
2026-05-13 docs: reconcile in-loop sensor architecture (SLF3S in controller; SDP→SEN0343 as one-time validation)
    The deployed device's in-loop shear sensor is now the Sensirion
    SLF3S-1300F inline liquid flow sensor (PEEK-wetted, in the controller
    body, reports flow + media temperature over the same I²C frame).
    Shear is mapped from measured flow via the locked Hagen-Poiseuille
    channel geometry, and the closed-loop PID runs on flow rather than
    on differential pressure.
    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
2026-05-13 Pre-public-release cleanup: depersonalize, finish sensor reconciliation, firmware integration, gitignore tweaks
    .gitignore + CITATION.cff
    - CITATION.cff added to .gitignore and removed from the index; held back
    from public release until ORCID and DOI fields are finalized.
    - examples/demo_study/runs/2026*/ added to .gitignore so per-experiment
    bench captures don't pollute the canonical demo data.
    examples/
    - quick_start_ignacio.md renamed to quick_start.md and rewritten in
    operator-generic third person (no second-person addressing of a
    specific collaborator). Sensor references swapped from SDP810 zero
    check to SLF3S zero-point verification. Cleaning workflow paragraph
    added point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
    [display.cpp, main.cpp]
